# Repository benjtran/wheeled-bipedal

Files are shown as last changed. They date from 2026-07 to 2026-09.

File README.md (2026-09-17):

# Wheeled Bipedal Robot

A custom wheeled-bipedal robot that uses articulated legs and a pair of driven wheels to raise its body and actively balance.

<figure>
    <figcaption>Figure 1: Robot in its standing pose</figcaption>
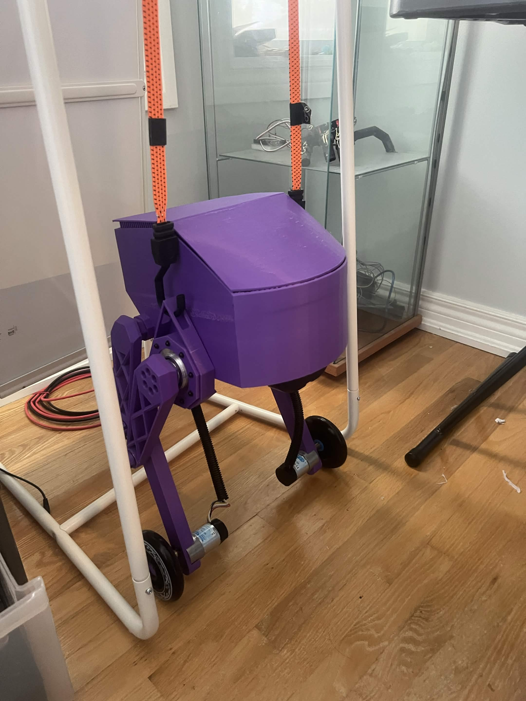
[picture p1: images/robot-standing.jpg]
Purple wheeled-bipedal robot standing in a support rig
    
</figure>

<figure>
    <figcaption>Figure 2: Early balance test</figcaption>
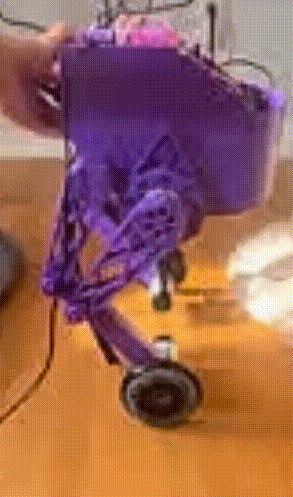
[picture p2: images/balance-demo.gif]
Wheeled-bipedal robot performing a balance test
    
</figure>

The project combines a parallel-linkage leg mechanism with a wheeled inverted-pendulum controller. The leg actuators set and hold the body height, while the wheel motors respond to pitch and wheel-speed feedback to keep the robot upright. The current firmware focuses on pose control, balance tuning, safety limits, and high-rate telemetry.

## Hardware

### Mechanical

The body, enclosure, wheel adapters, mounting plates, and leg linkages were custom-designed in Autodesk Inventor and manufactured primarily with 3D-printed parts. The leg geometry was first studied as a planar linkage before being transferred into the full CAD assembly.

<figure>
    <figcaption>Figure 3: Parallel-linkage motion study</figcaption>
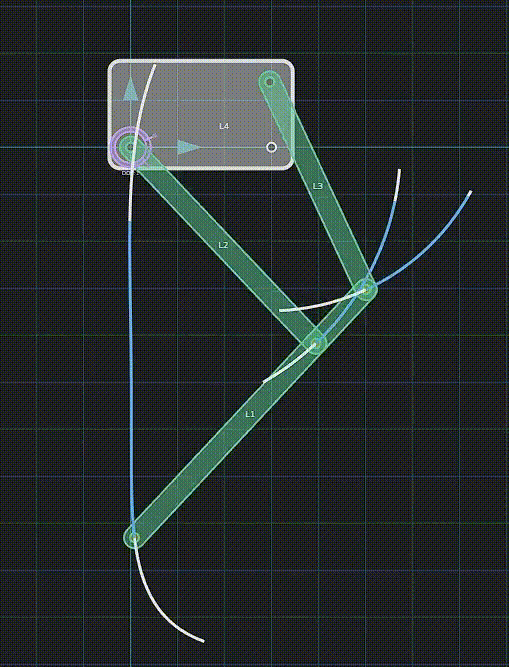
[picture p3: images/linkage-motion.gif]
Motion study of the robot leg linkage
    
</figure>

<figure>
    <figcaption>Figure 4: Robot in its lowered pose</figcaption>
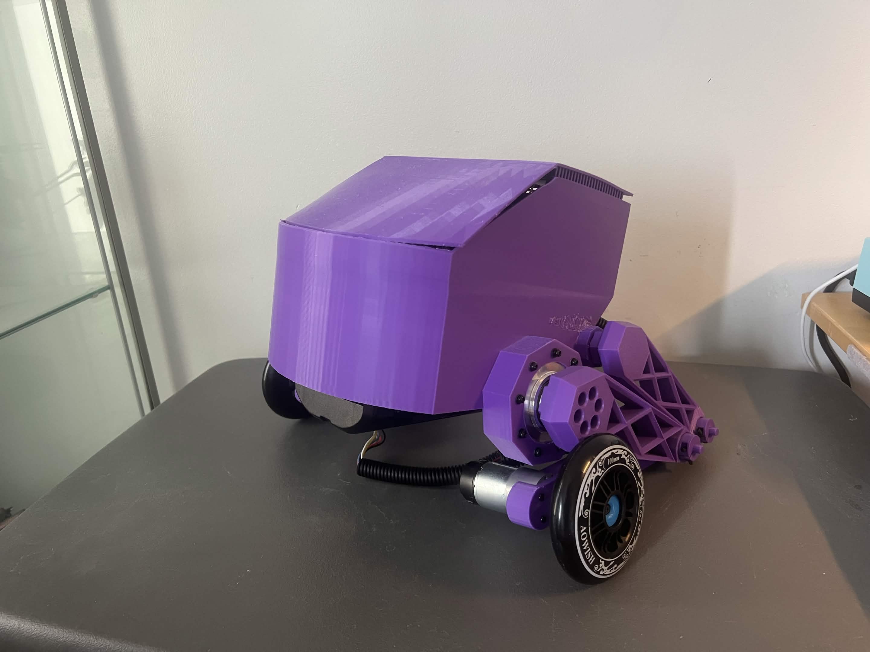
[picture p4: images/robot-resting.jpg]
Purple wheeled-bipedal robot in its lowered pose
    
</figure>

The native Autodesk Inventor part files are available in the [`parts`](parts/) folder.

### Electrical

- 1 x ESP32 development board
- 2 x RobStride 01 CAN smart actuators for the leg joints
- 2 x 37D 12 V, 50:1 geared DC motors with quadrature encoders
- 2 x BTS7960 H-bridge motor drivers
- 1 x MPU6050 six-axis IMU
- 2 x 100 mm wheels

## Software

1. **Pose control:** The ESP32 commands the two CAN joint actuators in position mode to raise the robot into its standing pose or lower it into its resting pose.

2. **Sensing:** The IMU provides acceleration and angular-rate measurements, while the wheel encoders provide wheel position and velocity feedback.

3. **State estimation:** A gyro-led complementary filter estimates body pitch. Accelerometer correction is gated during fast motion, and an online bias estimator compensates for slow gyro drift.

4. **Balance control:** A 200 Hz controller combines pitch error, pitch rate, integral correction, and wheel-velocity damping to calculate the wheel effort needed to stay upright.

5. **Motor output:** The wheel commands are converted to 20 kHz PWM signals for the two BTS7960 drivers. Both wheel motors receive the balance effort simultaneously.

6. **Safety:** A tip-over limit disables balancing and stops the wheels when the measured pitch moves outside the recoverable range. Serial kill commands provide an immediate manual stop.

7. **Tuning and telemetry:** Controller gains, pose targets, dead-zone compensation, and filter settings can be adjusted over serial without reflashing. The firmware can capture full-rate response traces for later analysis.

The [`tools/lqr_gains.py`](tools/lqr_gains.py) script estimates starting gain ratios from a wheeled inverted-pendulum model. The [`tools/capture_serial.py`](tools/capture_serial.py) utility provides an interactive serial terminal and saves telemetry bursts as CSV files.

## Repository Contents

- [`wheeled-bipedal.ino`](wheeled-bipedal.ino): main ESP32 firmware
- [`TWAI_CAN_MI_Motor.cpp`](TWAI_CAN_MI_Motor.cpp) and [`TWAI_CAN_MI_Motor.h`](TWAI_CAN_MI_Motor.h): CAN motor interface for the leg actuators
- [`tools`](tools/): balance-analysis and telemetry utilities
- [`parts`](parts/): Autodesk Inventor CAD part files
- [`images`](images/): project photos, demonstrations, and motion study

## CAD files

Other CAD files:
parts/BATTERY.ipt
parts/BATTERY_MOUNT_RETROFIT.ipt
parts/BODY.ipt
parts/BODY_ENCLOSURE.ipt
parts/BODY_V2.ipt
parts/Gearmotor_37D_100.ipt
parts/HARNESS.ipt
parts/LOWER_LINKAGE.ipt
parts/MOUNTING_PLATE.ipt
parts/MTN_PLATE_RETROFIT.ipt
parts/PARALLEL_LINKAGE_LH.ipt
parts/PARALLEL_LINKAGE_LH_V2.ipt
parts/UPPER_LINKAGE_LH.ipt
parts/UPPER_LINKAGE_LH_V2.ipt
parts/WHEEL.ipt
parts/WHEEL_ADAPTER.ipt
parts/WHEEL_ADAPTER_LID.ipt

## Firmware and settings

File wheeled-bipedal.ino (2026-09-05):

#include <Arduino.h>
#include <ESP32Encoder.h>
#include <Wire.h>
#include <math.h>
#include <ctype.h>
#include <stdlib.h>
#include <string.h>
#include "TWAI_CAN_MI_Motor.h"

// ==========================================================
//  PIN & CONFIG CONSTANTS
// ==========================================================
// ---- BTS7960 wheel drivers (replaces the L298N) ----
// Right motor - BTS7960 #1
const int R_RPWM = 25;
const int R_LPWM = 26;
// Left motor - BTS7960 #2
const int L_RPWM = 32;
const int L_LPWM = 33;
// R_EN / L_EN / VCC on both modules are wired straight to 3.3V,
// so both drivers are always enabled - nothing to drive for that in software.

// ---- Encoders ----
// Pin<->side mapping confirmed by the hardware test sketch: enc1 reads
// the RIGHT wheel and lives on 16/17, enc2 reads the LEFT wheel and
// lives on 34/35 (crossed from what the schematic would suggest).
const int M1_A = 16, M1_B = 17;   // right
const int M2_A = 34, M2_B = 35;   // left

const int I2C_SDA = 18, I2C_SCL = 19;
const byte IMU_ADDR = 0x68;

const int PWM_FREQ = 20000, PWM_RES = 10;
const int PWM_MAX  = (1 << PWM_RES) - 1;

// Gear ratio changed 270:1 -> 50:1. Assumes the encoder disc is still
// 64 CPR pre-gearbox like the old motors - verify against the new
// motor's datasheet if position/velocity numbers look off by a
// constant factor.
// The 37D "64 CPR" spec already includes 4x quadrature decoding (and
// attachFullQuad also decodes 4x), so counts/output-rev = 64 * 50 = 3200.
// (Was 64*4*50=12800, which double-counted quadrature and made every
// reported wheel speed read 4x too low - confirmed by a full-effort spin
// test reading 0.92 rev/s when the motor was actually doing ~3.7 rev/s.)
const float COUNTS_PER_OUTPUT_REV = 64.0 * 50.0;   // = 3200

const float CONTROL_HZ = 200.0;
const unsigned long CONTROL_US = 1000000UL / 200;

// ==========================================================
//  GLOBAL OBJECTS & STATE
// ==========================================================
ESP32Encoder enc1, enc2;
MI_Motor_ joint1, joint2;

struct RobotState {
  float pitch;
  float pitchRate;
  float wheelPosR, wheelPosL;
  float wheelVelR, wheelVelL;
};
RobotState state;

float gyroBiasX = 0, gyroBiasY = 0, gyroBiasZ = 0;
float gyroBiasEst = 0.0;   // ONLINE residual pitch-gyro bias, learned from the accel while
                           // near-upright (on top of the startup calibration); cancels the
                           // slow drift that made the estimate read "level" while leaning.
unsigned long loopCounter = 0;

// ==========================================================
//  JOINTS
// ==========================================================
const float J1_MIN = -0.319, J1_MAX = 0.233;
const float J2_MIN = -0.515, J2_MAX = 0.039;
float standJ1 = 0.21;
float standJ2 = -0.49;
const float POSE_SPEED = 0.3;
const float RELEASE_SPEED = 0.05;              // slower than POSE_SPEED, for a gentle lower
const unsigned long RELEASE_SETTLE_MS = 1500;  // time given to reach the rest position before cutting power

// "Down"/relaxed target angles - placeholders (currently just the opposite
// joint limits from the standing pose). Watch the first release and adjust
// restJ1/restJ2 to whatever position is actually "legs down" for your linkage.
float restJ1 = J1_MAX;
float restJ2 = J2_MIN;

bool jointsHolding = false;

float clampJ1(float v){ return v < J1_MIN ? J1_MIN : (v > J1_MAX ? J1_MAX : v); }
float clampJ2(float v){ return v < J2_MIN ? J2_MIN : (v > J2_MAX ? J2_MAX : v); }

// ==========================================================
//  BALANCE CONTROLLER + DEAD-ZONE COMPENSATION
// ==========================================================
bool  balanceEnabled = false;
float pitchSetpoint  = -4.0;

// NOTE: Kp/Kd/Ki, DEADZONE, and TIPOVER_LIMIT below are carried over
// unchanged from the 270:1 tune. The 50:1 gearboxes have roughly 5.4x
// less torque and 5.4x more free speed for the same effort value, so
// treat these as a starting point only - expect to re-tune all of
// them (and re-find DEADZONE's stiction point) once you start
// balancing on the new motors.
float Kp = 0.05;
float Kd = 0.05;
float Ki = 0.0;
float Kv = 0.0;        // wheel-velocity braking gain (opposes wheel spin to stop runaway; start 0, tune up)

float DEADZONE = 0.0;  // feedforward stiction comp. Leave 0 for balancing: any nonzero value
                       // injects a +/-DEADZONE bang-bang kick at the setpoint. Measured wheel
                       // stiction is ~0.14 if ever needed as a drive-mode feedforward.

float RATE_LP_ALPHA = 0.30;   // low-pass on gyro rate feeding the D term (0..1; lower = smoother, more lag)

// Overall control-sign multiplier. If the closed loop drives AWAY from the fall
// (robot dives off in one direction and diverges), the loop polarity is inverted
// somewhere (pitch or drive direction); set this to -1 to flip the whole control
// output at once. Live-tunable as "sign".
float CTRL_SIGN = 1.0;

// Dead-band (degrees). When the robot is within +/-PITCH_DB of the setpoint AND
// turning slowly, command zero effort so it stops fidgeting back and forth through
// the gearbox backlash (which sustains the jitter). 0 = off. Live-tunable 'pitchdb'.
float PITCH_DB = 0.0;

float integralError = 0.0;
float lastEffort = 0.0;
float lastRawEffort = 0.0;
float lastP = 0.0, lastD = 0.0, lastI = 0.0, lastV = 0.0;   // split-out control terms for telemetry
const float TIPOVER_LIMIT = 40.0;

// ---- Burst data logger ('L' captures a 2.5 s full-rate trace as CSV) ----
#define LOG_N 500
struct LogSample { float t, pitch, rate, rawEff, eff, P, D, V, wR, wL; };
LogSample logBuf[LOG_N];
int  logIdx = 0;
bool logging = false;
unsigned long logStartUs = 0;

void dumpLog() {
  Serial.println("---- LOG BEGIN (t_s,pitch,rate,rawEff,eff,P,D,V,wR,wL) ----");
  for (int i = 0; i < logIdx; i++) {
    Serial.printf("%.4f,%.3f,%.2f,%.4f,%.4f,%.4f,%.4f,%.4f,%.3f,%.3f\n",
                  logBuf[i].t, logBuf[i].pitch, logBuf[i].rate,
                  logBuf[i].rawEff, logBuf[i].eff, logBuf[i].P, logBuf[i].D,
                  logBuf[i].V, logBuf[i].wR, logBuf[i].wL);
  }
  Serial.println("---- LOG END ----");
}

// ==========================================================
//  MOTOR TEST MODE (bypasses balance to test raw motor response)
// ==========================================================
bool  motorTestMode = false;
float motorTestEffort = 0.0;

// ==========================================================
//  IMU
// ==========================================================
void imuInit() {
  Wire.beginTransmission(IMU_ADDR);
  Wire.write(0x6B); Wire.write(0x00);
  Wire.endTransmission();
}

void imuReadRaw(float &ax, float &ay, float &az, float &gx, float &gy, float &gz) {
  Wire.beginTransmission(IMU_ADDR);
  Wire.write(0x3B);
  Wire.endTransmission(false);
  Wire.requestFrom(IMU_ADDR, (uint8_t)14);
  int16_t rAx=(Wire.read()<<8)|Wire.read();
  int16_t rAy=(Wire.read()<<8)|Wire.read();
  int16_t rAz=(Wire.read()<<8)|Wire.read();
  Wire.read(); Wire.read();
  int16_t rGx=(Wire.read()<<8)|Wire.read();
  int16_t rGy=(Wire.read()<<8)|Wire.read();
  int16_t rGz=(Wire.read()<<8)|Wire.read();
  ax=rAx/16384.0; ay=rAy/16384.0; az=rAz/16384.0;
  gx=rGx/131.0;   gy=rGy/131.0;   gz=rGz/131.0;
}

void calibrateGyro(int samples = 500) {
  float sx=0, sy=0, sz=0;
  float ax,ay,az,gx,gy,gz;
  for (int i = 0; i < samples; i++) {
    imuReadRaw(ax,ay,az,gx,gy,gz);
    sx+=gx; sy+=gy; sz+=gz;
    delay(3);
  }
  gyroBiasX = sx/samples;
  gyroBiasY = sy/samples;
  gyroBiasZ = sz/samples;
}

float accelPitch(float ax, float ay, float az) {
  return atan2(ax, az) * 180.0 / PI;
}

// ==========================================================
//  BALANCE FUNCTION (with dead-zone comp)
// ==========================================================
float computeBalance(float dt) {
  float error = pitchSetpoint - state.pitch;
  float P = Kp * error;
  float D = Kd * (-state.pitchRate);

  integralError += error * dt;
  if (integralError >  50) integralError =  50;
  if (integralError < -50) integralError = -50;
  float I = Ki * integralError;

  // Wheel-velocity braking: opposes how fast the wheels are actually spinning.
  // Pure pitch feedback lets the wheels accumulate speed and run away (drive one
  // way, over-translate, throw the body past vertical). This term pulls effort
  // back toward zero wheel speed so the robot settles instead of running off.
  // Uses the correctly-scaled encoder velocity, lightly low-passed (it's quantized).
  static float wheelVelFilt = 0.0f;
  // Right encoder (enc1, pins 16/17) is currently dead (reads ~0). Both wheels
  // get identical effort and spin together, so the LEFT wheel speed alone is a
  // valid proxy for robot velocity. Revert to 0.5*(wheelVelR+wheelVelL) once the
  // right encoder wiring is fixed.
  float avgVel = state.wheelVelL;
  wheelVelFilt += 0.20f * (avgVel - wheelVelFilt);
  float V = -Kv * wheelVelFilt;

  // CTRL_SIGN flips only the pitch-based terms (P/D/I). The wheel-velocity brake
  // V must keep its own sign so it always OPPOSES wheel speed regardless of the
  // pitch-loop polarity (otherwise flipping the loop turns the brake into a
  // wheel-speed accelerator -> runaway).
  float effort = CTRL_SIGN * (P + D + I) + V;
  lastRawEffort = effort;
  lastP = P; lastD = D; lastI = I; lastV = V;

  // Backlash dead-band: if already close to balance and moving slowly, stop driving
  // so the wheels don't buzz back and forth across the gear slack.
  if (PITCH_DB > 0.0f && fabsf(error) < PITCH_DB && fabsf(state.pitchRate) < 20.0f)
    effort = 0.0f;

  if (effort >  1.0) effort =  1.0;
  if (effort < -1.0) effort = -1.0;

  if (DEADZONE > 0.0 && fabs(effort) > 0.001) {
    if (effort > 0)  effort = DEADZONE + (1.0 - DEADZONE) * effort;
    else             effort = -DEADZONE + (1.0 - DEADZONE) * effort;
  }
  return effort;
}

// ==========================================================
//  STATE ESTIMATION
// ==========================================================
void updateState(float dt) {
  float ax,ay,az,gx,gy,gz;
  imuReadRaw(ax,ay,az,gx,gy,gz);
  gx -= gyroBiasX; gy -= gyroBiasY; gz -= gyroBiasZ;

  // NOTE: gy is negated here. The IMU's gy has the OPPOSITE sign to the
  // accelerometer-derived pitch direction, so during fast motion (when the
  // complementary filter leans on the gyro) the estimate would invert and the
  // controller would drive the wrong way -> it could hold gentle leans but
  // never catch a real fall. Negating makes gyro agree with the accel at all
  // speeds. (Confirmed: robot fell backward while logged pitch went negative.)
  float gyroRate = -gy - gyroBiasEst;   // subtract the online-learned residual bias

  // --- Gyro-led complementary filter with accelerometer gating ---
  // Pitch integrates the RAW gyro (no filter lag on the angle itself).
  state.pitch += gyroRate * dt;

  // Correct toward the accelerometer tilt ONLY when the measured acceleration
  // is close to 1 g. During fast wheel moves the accelerometer also picks up
  // the robot's horizontal acceleration, so atan2(ax,az) lies (it can even
  // point the wrong way). Trusting it then drags the pitch estimate backwards
  // and the controller chases a phantom angle -> runaway. Gating it keeps the
  // estimate honest exactly when balancing needs it most.
  const float ACC_TRUST_BAND = 0.20f;   // use accel only within 0.20 g of gravity-only
  const float ACC_CORRECT    = 0.02f;   // correction strength. (0.05 was tried to fight gyro-bias
                                        // drift but it leaned too hard on the noisy accel and made
                                        // the estimate oscillate; use a small ki for the drift instead.)
  float accMag = sqrtf(ax*ax + ay*ay + az*az);   // in g
  if (fabsf(accMag - 1.0f) < ACC_TRUST_BAND) {
    float accAngle = accelPitch(ax, ay, az);
    float aerr = accAngle - state.pitch;
    state.pitch += ACC_CORRECT * aerr;      // fast proportional correction (unchanged)
    // Slowly learn the residual gyro bias from the same error. This is the Mahony
    // integral term: it drives the long-term drift to zero WITHOUT the noise that a
    // big proportional accel gain adds. Time constant ~ seconds.
    const float BIAS_KI = 0.30f;
    // Only learn the bias when NEARLY STILL. During the balancing wobble the accel is
    // motion-contaminated, so learning then teaches a wrong bias that accumulates over
    // a few seconds and eventually drops the robot ("turns off"). Learn it while
    // settling (before balance), then hold it steady through the wobble.
    if (fabsf(gyroRate) < 3.0f) {
      gyroBiasEst -= BIAS_KI * aerr * dt;
      if (gyroBiasEst >  5.0f) gyroBiasEst =  5.0f;   // clamp to +/-5 deg/s of learned bias
      if (gyroBiasEst < -5.0f) gyroBiasEst = -5.0f;
    }
  }

  // The D term needs a smoother rate: the raw gyro is too noisy to multiply by
  // Kd without amplifying noise into full-throttle wheel commands. A light
  // first-order low-pass keeps the lead (anticipation) while killing the jitter.
  static float rateFilt = 0.0f;
  rateFilt += RATE_LP_ALPHA * (gyroRate - rateFilt);
  state.pitchRate = rateFilt;

  static int64_t lastC1 = 0, lastC2 = 0;
  int64_t c1 =  enc1.getCount();
  int64_t c2 = -enc2.getCount();
  state.wheelPosR = (float)c1 / COUNTS_PER_OUTPUT_REV;
  state.wheelPosL = (float)c2 / COUNTS_PER_OUTPUT_REV;
  state.wheelVelR = ((float)(c1 - lastC1) / COUNTS_PER_OUTPUT_REV) / dt;
  state.wheelVelL = ((float)(c2 - lastC2) / COUNTS_PER_OUTPUT_REV) / dt;
  lastC1 = c1; lastC2 = c2;
}

void initStateEstimate() {
  float ax,ay,az,gx,gy,gz;
  imuReadRaw(ax,ay,az,gx,gy,gz);
  state.pitch = accelPitch(ax, ay, az);
  state.pitchRate = 0;
}

// ==========================================================
//  WHEEL MOTORS (BTS7960: two PWM pins per motor, no direction pin)
// ==========================================================
void setWheelR(float effort) {
  effort = constrain(effort, -1.0f, 1.0f);
  int duty = (int)(fabs(effort) * PWM_MAX);
  if (effort > 0.001f) {
    ledcWrite(R_RPWM, duty);
    ledcWrite(R_LPWM, 0);
  } else if (effort < -0.001f) {
    ledcWrite(R_RPWM, 0);
    ledcWrite(R_LPWM, duty);
  } else {
    ledcWrite(R_RPWM, 0);
    ledcWrite(R_LPWM, 0);
  }
}
void setWheelL(float effort) {
  effort = constrain(effort, -1.0f, 1.0f);
  int duty = (int)(fabs(effort) * PWM_MAX);
  if (effort > 0.001f) {
    ledcWrite(L_RPWM, duty);
    ledcWrite(L_LPWM, 0);
  } else if (effort < -0.001f) {
    ledcWrite(L_RPWM, 0);
    ledcWrite(L_LPWM, duty);
  } else {
    ledcWrite(L_RPWM, 0);
    ledcWrite(L_LPWM, 0);
  }
}
void stopWheels() { setWheelR(0); setWheelL(0); }

// ==========================================================
//  JOINT MOTORS
// ==========================================================
void prepJoint(MI_Motor_ &m, uint8_t id) {
  m.Motor_Con_Init(id); delay(100);
  m.Motor_Reset();      delay(200);
}
void holdPose() {
  float t1 = clampJ1(standJ1);
  float t2 = clampJ2(standJ2);
  joint1.Change_Mode(POS_MODE); delay(50);
  joint1.Motor_Enable();        delay(50);
  joint2.Change_Mode(POS_MODE); delay(50);
  joint2.Motor_Enable();        delay(50);
  joint1.Set_PosMode(t1, POSE_SPEED);
  joint2.Set_PosMode(t2, POSE_SPEED);
  jointsHolding = true;
  Serial.printf(">>> HOLDING POSE: j1=%.3f j2=%.3f <<<\n", t1, t2);
}
void releaseJoints() {
  float r1 = clampJ1(restJ1);
  float r2 = clampJ2(restJ2);

  Serial.println(">>> LOWERING JOINTS <<<");
  joint1.Set_PosMode(r1, RELEASE_SPEED);
  joint2.Set_PosMode(r2, RELEASE_SPEED);

  unsigned long start = millis();
  while (millis() - start < RELEASE_SETTLE_MS) {
    pollJoint(joint1);
    pollJoint(joint2);
    delay(20);
  }

  joint1.Motor_Reset();
  joint2.Motor_Reset();
  jointsHolding = false;
  Serial.println(">>> JOINTS RELEASED <<<");
}
void pollJoint(MI_Motor_ &m) { m.Motor_Data_Updata(1); }

// ==========================================================
//  KEYBOARD
// ==========================================================
void handleKey(char c) {
  switch (c) {
    case 'H': holdPose();      break;
    case 'R': releaseJoints(); break;
    case 'B': balanceEnabled = true; motorTestMode = false; integralError = 0;
              Serial.println(">>> BALANCE ON <<<"); break;
    case ' ':
    case 'K': balanceEnabled = false; motorTestMode = false; stopWheels();
              Serial.println(">>> KILL <<<"); break;

    // ---- capture a 2.5 s full-rate trace of the balance response ----
    case 'L': logIdx = 0; logging = true; logStartUs = micros();
              Serial.println(">>> LOGGING 2.5s... <<<"); break;

    // ---- MOTOR TEST MODE: directly command wheel effort, bypass balance ----
    case 'T': motorTestMode = true; balanceEnabled = false; motorTestEffort = 0;
              Serial.println(">>> MOTOR TEST MODE (balance off) <<<"); break;
    case '1': motorTestEffort = 0.1;  Serial.println("effort=0.1"); break;
    case '2': motorTestEffort = 0.2;  Serial.println("effort=0.2"); break;
    case '3': motorTestEffort = 0.3;  Serial.println("effort=0.3"); break;
    case '5': motorTestEffort = 0.5;  Serial.println("effort=0.5"); break;
    case '9': motorTestEffort = 1.0;  Serial.println("effort=1.0"); break;
    case '0': motorTestEffort = 0.0;  Serial.println("effort=0.0"); break;
    case '-': motorTestEffort = -motorTestEffort;
              Serial.printf("effort=%.1f (flipped)\n", motorTestEffort); break;
  }
}

// ==========================================================
//  LIVE TUNING OVER SERIAL
// ==========================================================
// Type "<name> <value>" and press Enter to change a value without
// reflashing, e.g.  kp 0.08   or   deadzone 0.15
// Type "list" to print current values.
struct TunableParam {
  const char* name;
  float* value;
};

TunableParam tunables[] = {
  {"kp",       &Kp},
  {"kd",       &Kd},
  {"ki",       &Ki},
  {"kv",       &Kv},
  {"ratelp",   &RATE_LP_ALPHA},
  {"sign",     &CTRL_SIGN},
  {"pitchdb",  &PITCH_DB},
  {"deadzone", &DEADZONE},
  {"setpoint", &pitchSetpoint},
  {"standj1",  &standJ1},
  {"standj2",  &standJ2},
  {"effort",   &motorTestEffort},   // fine T-mode effort, e.g. "effort 0.06" (T mode must be on)
};
const int NUM_TUNABLES = sizeof(tunables) / sizeof(tunables[0]);

void printTunables() {
  Serial.println("---- current tuning values ----");
  for (int i = 0; i < NUM_TUNABLES; i++) {
    Serial.printf("  %-9s = %.4f\n", tunables[i].name, *(tunables[i].value));
  }
  Serial.println("Set with: <name> <value>   e.g. kp 0.08   (type 'list' to see this again)");
  Serial.println("--------------------------------");
}

bool namesMatch(const char* a, const char* b) {
  while (*a && *b) {
    if (tolower(*a) != tolower(*b)) return false;
    a++; b++;
  }
  return *a == '\0' && *b == '\0';
}
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
void loop() {
  readSerialCommands();

  static unsigned long lastControlUs = 0;
  unsigned long nowUs = micros();

  if (nowUs - lastControlUs >= CONTROL_US) {
    float dt = (nowUs - lastControlUs) / 1000000.0;
    lastControlUs = nowUs;
    loopCounter++;

    updateState(dt);

    if (balanceEnabled &&
        fabs(state.pitch - pitchSetpoint) > TIPOVER_LIMIT) {
      balanceEnabled = false;
      integralError = 0;
    }

    if (motorTestMode) {
      lastEffort = motorTestEffort;
      setWheelR(motorTestEffort);
      setWheelL(motorTestEffort);
    } else if (balanceEnabled) {
      lastEffort = computeBalance(dt);
      setWheelR(lastEffort);
      setWheelL(lastEffort);
    } else {
      stopWheels();
      integralError = 0;
      lastEffort = 0.0;
    }

    // ---- burst logger: record every control tick while active ----
    if (logging) {
      if (logIdx < LOG_N) {
        logBuf[logIdx].t      = (nowUs - logStartUs) / 1000000.0;
        logBuf[logIdx].pitch  = state.pitch;
        logBuf[logIdx].rate   = state.pitchRate;
        logBuf[logIdx].rawEff = lastRawEffort;
        logBuf[logIdx].eff    = lastEffort;
        logBuf[logIdx].P      = lastP;
        logBuf[logIdx].D      = lastD;
        logBuf[logIdx].V      = lastV;
        logBuf[logIdx].wR     = state.wheelVelR;
        logBuf[logIdx].wL     = state.wheelVelL;
        logIdx++;
      } else {
        logging = false;
        dumpLog();
      }
    }
  }

  // ---- housekeeping ----
  static unsigned long lastPoll = 0;
  if (millis() - lastPoll >= 100) {
    lastPoll = millis();
    pollJoint(joint1);
    pollJoint(joint2);
  }

  static unsigned long lastPrint = 0;
  if (millis() - lastPrint >= 100) {
    lastPrint = millis();
    const char* mode = motorTestMode ? "TEST" : (balanceEnabled ? "BAL" : "off");
    Serial.printf("pitch=%.2f rate=%.1f bias=%.2f P=%.2f D=%.2f V=%.2f rawEff=%.2f eff=%.2f wR=%.2f wL=%.2f | j1cmd=%.3f j1act=%.3f j2cmd=%.3f j2act=%.3f [%s]\n",
                  state.pitch, state.pitchRate, gyroBiasEst, lastP, lastD, lastV, lastRawEffort, lastEffort,
                  state.wheelVelR, state.wheelVelL,
                  standJ1, joint1.motor_rx_data.cur_angle,
                  standJ2, joint2.motor_rx_data.cur_angle, mode);
  }

  static unsigned long lastRateCheck = 0;
  static unsigned long lastLoopCount = 0;
  if (millis() - lastRateCheck >= 2000) {
    unsigned long rate = (loopCounter - lastLoopCount) / 2;
    lastLoopCount = loopCounter;
    lastRateCheck = millis();
    Serial.printf(">>> loop rate: %lu Hz <<<\n", rate);
  }
}

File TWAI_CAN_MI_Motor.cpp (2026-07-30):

#include "Arduino.h"
#include "TWAI_CAN_MI_Motor.h"

//把浮点数转换成uint_16 用在位置 扭矩 上面
static int float_to_uint(float x, float x_min, float x_max, int bits)
{
  float span = x_max - x_min;
  float offset = x_min;
  if (x > x_max) x = x_max;
  else if (x < x_min) x = x_min;
  return (int)((x - offset) * ((float)((1 << bits) - 1)) / span);
}

//底层的CAN发送指令，小米电机采用扩展帧，数据帧的格式
static void CAN_Send_Frame(can_frame_t* frame)
{
    CanFrame obdFrame = { 0 };
    uint32_t id_val, data_val, mode_val;
    uint32_t combined_val;

    obdFrame.extd = 1;              //0-标准帧; 1-扩展帧
    obdFrame.rtr = 0;               //0-数据帧; 1-远程帧
    obdFrame.ss = 0;                //0-错误重发; 1-单次发送(仲裁或丢失时消息不会被重发)，对接收消息无效
    obdFrame.self = 0;              //0-不接收自己发送的消息，1-接收自己发送的消息，对接收消息无效
    obdFrame.dlc_non_comp = 0;      //0-数据长度不大于8(ISO 11898-1); 1-数据长度大于8(非标);

    //拼接ID
    id_val = frame->id;
    data_val = frame->data;
    mode_val = frame->mode;
    combined_val |= (mode_val << 24);
    combined_val |= (data_val << 8);
    combined_val |= id_val;

    obdFrame.identifier = combined_val; //普通帧直接写id，扩展帧需要计算。11/29位ID
    obdFrame.data_length_code = 8;      //要发送的字节数

    for (int i = 0; i < 8; i++)
    {
        obdFrame.data[i] = frame->tx_data[i];
    }
    ESP32Can.writeFrame(obdFrame);
}

/**
      * @brief          电机使能
      */
void MI_Motor_::Motor_Enable(void)
{
    can_frame_t motor_con_frame;
    motor_con_frame.mode = 3;           //模式3，使能
    motor_con_frame.id = this->id;      //目标电机ID
    motor_con_frame.data = MASTER_ID;   //本机ID
    for (int i = 0; i < 8; i++)
    {
        motor_con_frame.tx_data[i] = 0;
    }
    CAN_Send_Frame(&motor_con_frame);
}

/**
      * @brief          电机停止
      */
void MI_Motor_::Motor_Reset(void)
{
    can_frame_t motor_con_frame;
    motor_con_frame.mode = 4;           //模式4，停止
    motor_con_frame.id = this->id;      //目标电机ID
    motor_con_frame.data = MASTER_ID;   //本机ID
    for (int i = 0; i < 8; i++)
    {
        motor_con_frame.tx_data[i] = 0;
    }
    CAN_Send_Frame(&motor_con_frame);
}

/**
      * @brief          设置电机机械零点
      */
void MI_Motor_::Motor_Set_Zero(void)
{
    can_frame_t motor_con_frame;
    motor_con_frame.mode = 6;           //模式6，设置零点
    motor_con_frame.id = this->id;      //目标电机ID
    motor_con_frame.data = MASTER_ID;   //本机ID
    for (int i = 0; i < 8; i++)
    {
        motor_con_frame.tx_data[i] = 0;
    }
    CAN_Send_Frame(&motor_con_frame);
}

/**
      * @brief          运动控制模式
      * @param[in]      torque 扭矩，N·m，-12到+12
      * @param[in]      MechPosition 角度，rad，-12.5到+12.5
      * @param[in]      speed 角速度，rad/s，-30到+30
      * @param[in]      kp 比例增益，0到500
      * @param[in]      kd 微分增益，0到5
      */
void MI_Motor_::Motor_ControlMode(float torque, float MechPosition, float speed, float kp, float kd)
{
    can_frame_t motor_con_frame;
    motor_con_frame.mode = 1;           //模式1,运控模式
    motor_con_frame.id = this->id;      //目标电机ID
    motor_con_frame.data = float_to_uint(torque, T_MIN, T_MAX, 16);

    motor_con_frame.tx_data[0] = float_to_uint(MechPosition, P_MIN, P_MAX, 16) >> 8;
    motor_con_frame.tx_data[1] = float_to_uint(MechPosition, P_MIN, P_MAX, 16);
    motor_con_frame.tx_data[2] = float_to_uint(speed, V_MIN, V_MAX, 16) >> 8;
    motor_con_frame.tx_data[3] = float_to_uint(speed, V_MIN, V_MAX, 16);
    motor_con_frame.tx_data[4] = float_to_uint(kp, KP_MIN, KP_MAX, 16) >> 8;
    motor_con_frame.tx_data[5] = float_to_uint(kp, KP_MIN, KP_MAX, 16);
    motor_con_frame.tx_data[6] = float_to_uint(kd, KD_MIN, KD_MAX, 16) >> 8;
    motor_con_frame.tx_data[7] = float_to_uint(kd, KD_MIN, KD_MAX, 16);
    CAN_Send_Frame(&motor_con_frame);
}

/**
      * @brief          设置单参数
      * @param[in]      parameter 参数数据
      * @param[in]      index 参数列表，详见电机说明书的4.1.11
      */
void MI_Motor_::Set_SingleParameter(uint16_t parameter, float index)
{
    can_frame_t motor_con_frame;
    motor_con_frame.mode = 18;          //模式18,单参数修改模式
    motor_con_frame.id = this->id;      //目标电机ID
    motor_con_frame.data = MASTER_ID;   //来标识主CAN_ID

    motor_con_frame.tx_data[2] = 0;
    motor_con_frame.tx_data[3] = 0;     //Byte2~3: 00

    memcpy(&motor_con_frame.tx_data[0], &parameter, 2);   //Byte0~1: index，参数列表详见4.1.11
    memcpy(&motor_con_frame.tx_data[4], &index, 4);       //Byte4~7: 参数数据，1字节数据在Byte4
    CAN_Send_Frame(&motor_con_frame);
}

/**
      * @brief          解析电机发送数据包
      * @param[in]      can_Frame_point CAN原始数据包的指针
      * @param[in]      motor_frame_point 电机解析数据包的指针
      */
void MI_Motor_::Decoding_Motor_data(CanFrame* can_Frame_point, can_rx_frame_t* motor_frame_point)
{
    motor_frame_point->master_id = RX_29ID_DISASSEMBLE_MASTER_ID(can_Frame_point->identifier);
    motor_frame_point->motor_id = RX_29ID_DISASSEMBLE_MOTOR_ID(can_Frame_point->identifier);
    motor_frame_point->err_sta = RX_29ID_DISASSEMBLE_ERR_STA(can_Frame_point->identifier);
    motor_frame_point->HALL_err = RX_29ID_DISASSEMBLE_HALL_ERR(can_Frame_point->identifier);
    motor_frame_point->magnet_err = RX_29ID_DISASSEMBLE_MAGNET_ERR(can_Frame_point->identifier);
    motor_frame_point->temp_err = RX_29ID_DISASSEMBLE_TEMP_ERR(can_Frame_point->identifier);
    motor_frame_point->current_err = RX_29ID_DISASSEMBLE_CURRENT_ERR(can_Frame_point->identifier);
    motor_frame_point->voltage_err = RX_29ID_DISASSEMBLE_VOLTAGE_ERR(can_Frame_point->identifier);
    motor_frame_point->mode_sta = RX_29ID_DISASSEMBLE_MODE_STA(can_Frame_point->identifier);

    //弧度单位
    motor_frame_point->cur_angle = RX_DATA_DISASSEMBLE_CUR_ANGLE(can_Frame_point->data) * INT2ANGLE - 4 * PI;
    motor_frame_point->cur_speed = RX_DATA_DISASSEMBLE_CUR_SPEED(can_Frame_point->data) * INT2SPEED - 30;
    motor_frame_point->cur_torque = RX_DATA_DISASSEMBLE_CUR_TORQUE(can_Frame_point->data) * INT2TORQUE - 12;
    motor_frame_point->cur_temp = RX_DATA_DISASSEMBLE_CUR_TEMP(can_Frame_point->data) / 10.0f;
}

/**
      * @brief          设置速度模式的参数
      * @param[in]      speed 角速度，rad/s，-30到+30
      */
void MI_Motor_::Set_SpeedMode(float speed)
{
    Set_SingleParameter(SPD_REF, speed);
}

/**
      * @brief          设置位置模式的参数
      * @param[in]      position 角度，rad，-12.5到+12.5
      * @param[in]      max_speed 角速度，rad/s，0到+30
      */
void MI_Motor_::Set_PosMode(float position, float max_speed)
{
    Set_SingleParameter(LIMIT_SPD, max_speed);
    Set_SingleParameter(LOC_REF, position);
}

/**
      * @brief          设置电流模式的参数
      * @param[in]      current 电流，A，-23到+23
      */
void MI_Motor_::Set_CurMode(float current)
{
    Set_SingleParameter(IQ_REF, current);
}
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

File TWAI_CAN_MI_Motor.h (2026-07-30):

#ifndef _TWAI_CAN_MI_MOTOR_H__
#define _TWAI_CAN_MI_MOTOR_H__

/*
    小米电机驱动器通信协议及使用说明

    电机通信为 CAN 2.0 通信接口，波特率 1Mbps，采用扩展帧格式，如下所示：
    数据域          29 位 ID        8Byte 数据区
    大小 Bit28~bit24 bit23~8 bit7~0 Byte0~Byte7
    描述 通信类型 数据区 2 目标地址 数据区 1

    电机支持的控制模式包括：
    运控模式：给定电机运控 5 个参数；
    电流模式：给定电机指定的 Iq 电流；
    速度模式：给定电机指定的运行速度；
    位置模式：给定电机指定的位置，电机将运行到该指定的位置；

    本台测试用的小米电机CAN ID=1，主机ID=0

    注意配置顺序：
        1. 电机CAN初始化->电机ID初始化->设定电机机械零点->设置电机控制模式->设置对应模式的控制参数->使能(启动)电机
        2. 必须给电机发数据才会有数据返回

    测试用例：
    MI_Motor_ M1_con;

    void setup() {
        Motor_CAN_Init();
        M1_con.Motor_Con_Init(MOTER_1_ID);
        M1_con.Motor_Set_Zero();
        M1_con.Change_Mode(SPEED_MODE);
        M1_con.Motor_Enable();
    }

    void loop() {
        M1_con.Motor_Data_Updata(20);
        Serial.printf("M1数据: %d,%d,%d,%d,%d,%d,%d,%d,%d,angle:%.2f,speed:%.2f,torque:%.2f,temp:%.2f,\r\n",
                                      M1_con.motor_rx_data.master_id,M1_con.motor_rx_data.motor_id,
                                      M1_con.motor_rx_data.err_sta,M1_con.motor_rx_data.HALL_err,
                                      M1_con.motor_rx_data.magnet_err,M1_con.motor_rx_data.temp_err,
                                      M1_con.motor_rx_data.current_err,M1_con.motor_rx_data.voltage_err,
                                      M1_con.motor_rx_data.mode_sta,
                                      M1_con.motor_rx_data.cur_angle,M1_con.motor_rx_data.cur_speed,
                                      M1_con.motor_rx_data.cur_torque,M1_con.motor_rx_data.cur_temp);
        M1_con.Set_SpeedMode(-1);
        vTaskDelay(20);
    }
*/

#include "Arduino.h"
#include <ESP32-TWAI-CAN.hpp>

/*CAN设置*/
#define CAN_TX          13
#define CAN_RX          4

#define MASTER_ID       0
#define MOTER_1_ID      127
#define MOTER_2_ID      1

/*基础配置*/
#define P_MIN           -12.5f
#define P_MAX           12.5f
#define V_MIN           -30.0f
#define V_MAX           30.0f
#define KP_MIN          0.0f
#define KP_MAX          500.0f
#define KD_MIN          0.0f
#define KD_MAX          5.0f
#define T_MIN           -12.0f
#define T_MAX           12.0f

/*数据配置*/
#define RUN_MODE        0x7005    // 运行模式, uint8, 1字节, 0运控模式,1位置模式，2速度模式，3电流模式
#define CTRL_MODE       0
#define POS_MODE        1
#define SPEED_MODE      2
#define CUR_MODE        3
#define IQ_REF          0x7006    // 电流模式 Iq 指令, float, 4字节, -23~23A
#define SPD_REF         0x700A    // 转速模式转速指令, float, 4字节, -30~30rad/s
#define LIMIT_TORQUE    0x700B    // 转矩限制, float, 4字节, 0~12Nm
#define CUR_KP          0x7010    // 电流的 Kp, float, 4字节, 默认值 0.125
#define CUR_KI          0x7011    // 电流的 Ki, float, 4字节, 默认值 0.0158
#define CUR_FILT_GAIN   0x7014    // 电流滤波系数 filt_gain, float, 4字节, 0~1.0，默认值 0.1
#define LOC_REF         0x7016    // 位置模式角度指令, float, 4字节, rad
#define LIMIT_SPD       0x7017    // 位置模式速度限制, float, 4字节, 0~30rad/s
#define LIMIT_CUR       0x7018    // 速度位置模式电流限制, float, 4字节, 0~23A
#define MECH_POS        0x7019    // 负载端计圈机械角度, float, 4字节, rad, 只读
#define IQF             0x701A    // iq 滤波值, float, 4字节, -23~23A, 只读
#define MECH_VEL        0x701B    // 负载端转速, float, 4字节, -30~30rad/s, 只读
#define VBUS            0x701C    // 母线电压, float, 4字节, V, 只读
#define ROTATION        0x701D    // 圈数, int16, 2字节, 圈数, 可读写
#define LOC_KP          0x701E    // 位置的 kp, float, 4字节, 默认值 30, 可读写
#define SPD_KP          0x701F    // 速度的 kp, float, 4字节, 默认值 1, 可读写
#define SPD_KI          0x7020    // 速度的 ki, float, 4字节, 默认值 0.002, 可读写
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

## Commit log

2026-07-30 stable fused pitch with gyro + accel complementary filter
2026-09-02 Add balance-tuning telemetry, CSV burst logger, and serial capture tool
    Firmware (wheeled-bipedal.ino):
    - Split PID into P/D/I terms and expose them in the live status print
    - Print commanded vs actual joint angles (j1/j2 cmd/act) for pose diagnosis
    - Add 'L' burst logger: 2.5s @200Hz trace of pitch,rate,rawEff,eff,P,D,wR,wL,
    emitted as a delimited CSV block over serial
    - Wire.setClock(400000) to reduce MPU6050 read latency
    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
2026-09-03 Fix balance estimator + controller: accel gating, gyro-rate LPF, wheel-velocity term
    State estimator:
    - Gyro-led complementary filter with accelerometer gating: only apply the
    accel tilt correction when |accel| is within 0.20 g of gravity, so hard
    wheel accelerations no longer corrupt the pitch estimate (was causing the
    estimate to lag/point the wrong way during exactly the maneuvers balancing
    needs -> runaway).
    - Low-pass filter the gyro rate feeding the D term (raw gyro was too noisy;
    high Kd slammed the wheels on noise). Pitch still integrates the raw gyro.
    Controller:
    - Add wheel-velocity braking term (-Kv * filtered avg wheel speed) to stop the
    pure-pitch runaway; uses the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
    [wheeled-bipedal.ino]
2026-09-03 Add live control-sign flip for polarity + LQR starting-gain tool
    - Add CTRL_SIGN multiplier (live-tunable 'sign') on the summed control effort so
    closed-loop polarity can be flipped in-place (set 'sign -1') without reflashing,
    to resolve whether the loop drives toward or away from the fall.
    - tools/lqr_gains.py: computes starting kp/kd/kv from a wheeled-inverted-pendulum
    model (mass, CoM height, wheel radius) via LQR; reports gains in sketch units
    and their ratio for the scale-by-one-knob tuning method.
    [lqr_gains.py, wheeled-bipedal.ino]
2026-09-03 Apply CTRL_SIGN only to pitch terms so it doesn't invert the wheel-velocity brake
    Confirmed from a session-log trace: with sign=-1 the robot finally caught the tilt (pitch fell from 3.4 to ~1 deg and held ~0.4s), proving the pitch-loop polarity was inverted. But flipping the whole effort also flipped V into positive feedback (wheel-speed runaway). Now: effort = CTRL_SIGN*(P+D+I) + V, so the velocity brake keeps its correct sign and kv stays positive/intuitive.
    [wheeled-bipedal.ino]
2026-09-03 Negate gyro rate: fixes inverted pitch estimate during fast motion
    The IMU gy had opposite sign to the accel-derived pitch. With accel gating, the estimate was accel-correct at rest but gyro-inverted during fast motion, so the robot could hold gentle leans but never catch a real fall (and logged pitch read opposite to the physical fall direction - confirmed: fell backward while pitch went negative). Negating gyro makes the estimate consistent at all speeds. With a correct estimator the control sign should now be +1 per calibration (forward tilt=pitch down, +effort=drive forward).
    [wheeled-bipedal.ino]
2026-09-05 Restore ~200Hz control loop: non-blocking serial TX + slower print/poll
    The 50ms status print (and 50ms joint CAN poll) were stalling the 5ms control tick, dropping the loop to ~160Hz and costing phase margin (worsening the balance limit cycle). Enlarge Serial TX buffer to 1024 so printf never blocks, and drop the status print and joint poll from 50ms to 100ms. Control math is unchanged.
    [wheeled-bipedal.ino]
2026-09-05 Velocity term uses left encoder only (right encoder pins 16/17 dead)
    Right wheel encoder currently reads ~0 (motor spins fine, both wheels driven by identical effort). Use wheelVelL alone as the robot-velocity proxy for the kv term so a dead right encoder doesn't feed it a half-value. Revert to the average once the right encoder wiring is fixed.
    [wheeled-bipedal.ino]
2026-09-05 Raise accel correction 0.02->0.05 to null residual gyro-bias drift
    Robot balances well near setpoint but the gyro still reads ~-1.5 deg/s at rest; the residual bias slowly leans the pitch estimate and it falls after a few seconds. Stronger accel correction (active while near-upright, |accel|~1g) continuously pulls the estimate back to gravity truth, countering the drift.
    [wheeled-bipedal.ino]
2026-09-05 Revert accel correction to 0.02 (0.05 added estimate noise -> oscillation)
    Raising ACC_CORRECT to 0.05 made the pitch estimate lean too hard on the noisy/motion-contaminated accelerometer, producing a growing wobble that fell faster than before. Back to 0.02. The slow gyro-bias drift will be handled with a small ki term instead, which nulls steady lean without injecting sensor noise.
    [wheeled-bipedal.ino]
2026-09-05 Add online gyro-bias estimation (Mahony integral) to stop drift-and-fall
    Robot balanced tightly ~1s then silently toppled without correcting: the ~1.5 deg/s gyro bias slowly drifted the pitch estimate, so it read 'level' while physically leaning, and the controller commanded ~0 effort as it fell. ki couldn't help (it acts on the drifted estimate error, which reads ~0). Fix: while near-upright (|accel|~1g), slowly integrate the accel-vs-estimate error into gyroBiasEst and subtract it from the gyro rate (Mahony bias-feedback). Cancels drift at the source without the noise of a large proportional accel gain. Clamped to +/-5 deg/s.
    [wheeled-bipedal.ino]
2026-09-05 Only learn gyro bias when near-still; expose bias in telemetry
    The online bias estimator was learning during the balancing wobble, where the accel is motion-contaminated -> it accumulated a wrong bias over ~3s and dropped the robot ('turned off'). Gate learning to |rate|<3 deg/s so it learns while settling and holds steady during the wobble. Also print gyroBiasEst so we can watch it converge/hold.
    [wheeled-bipedal.ino]
2026-09-05 Add tunable pitch dead-band to quiet backlash limit-cycle jitter
    Jitter persists with low kd and heavy rate smoothing -> it's the 50:1 gearbox backlash, not the D term. Add a dead-band: within +/-PITCH_DB of setpoint and turning slowly (<20 deg/s), command zero effort so the wheels stop reversing across the gear slack. Live-tunable 'pitchdb' (0=off).
    [wheeled-bipedal.ino]
2026-09-09 Add wheel-mount counterbored-adapter fix design doc
2026-09-17 Expand README and add project media and CAD parts
    [BATTERY.ipt, BATTERY_MOUNT_RETROFIT.ipt, BODY.ipt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]
